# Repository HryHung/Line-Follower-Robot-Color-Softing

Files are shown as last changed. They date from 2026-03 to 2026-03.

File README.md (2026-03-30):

# Line Following AGV Robot (Color-Based Distribution)

Mobile robot designed for line tracking and automatic goods sorting based on color.  
This project demonstrates practical applications of control theory, embedded systems, and mechatronics design.

---
 robot
##  Overview

This project focuses on building a line-following robot with:

- Embedded firmware for real-time control  
- Line tracking using IR sensor array  
- Color detection for decision making  
- Autonomous navigation and delivery  

---

##  Guide

- You will need 2 esp32 devkit: 1 for robot & 1 for the controller
- Custom PCB is not requirement, you can replace by pegboard
- The Robot base is CNC
aluminium, you can replace by other material like: mica, 3d printed,...
- Matlab file are only for PID and visual check, you guys with need to PID your DC motor before run.

---

##  System Architecture

### Hardware

- Differential drive mobile platform  
- DC motors with encoders  
- IR sensor array (line detection)  
- Color sensor (Red / Blue detection)  
- Motor driver (TB6612FNG)  
- Microcontroller (STM32 / ESP32)  
- Battery + power management  

### Software Stack

```
[ High-Level Logic ]
        ↓
[ Decision Making (Color Detection) ]
        ↓
[ Line Tracking Algorithm ]
        ↓
[ PID Motor Control ]
        ↓
[ Hardware Drivers (PWM / ADC / GPIO) ]
```

---

##  Features

- Accurate line following (±3 mm error)  
- Autonomous color-based sorting  
- PID-based motor control  
- Modular hardware & software design  
- Suitable for robotics learning and R&D  

---

##  Technologies

- Embedded C  
- ESP32  
- PWM / ADC / GPIO  
- SolidWorks
- MATLAB / Simulink (modeling & control)  

---

##  Control Concept

- Line position estimated using weighted sensor readings  
- PID controller used for trajectory correction  
- State machine handles robot behavior:

```
Idle → Follow Line → Detect Load → Detect Color
     → Navigate → Stop at Destination
```

---

##  Specifications

- Speed ≥ 0.1 m/s  
- Line width: 26 mm  
- Tracking error: ±3 mm  
- Stopping error: ±5 mm  
- Load capacity: ~1 kg

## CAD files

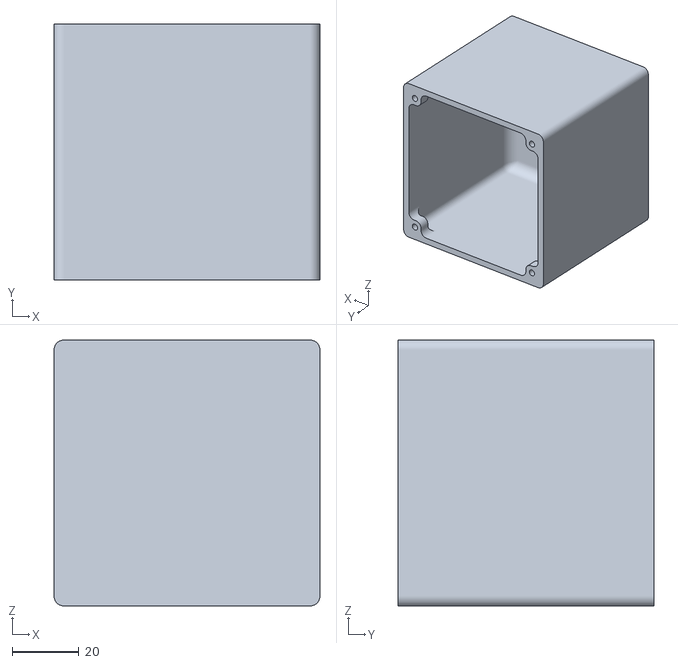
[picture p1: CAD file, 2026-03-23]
Mechanical/Robot V2/Thân khối hàng_màu đỏ.STL
80.0 x 77.0 x 80.0

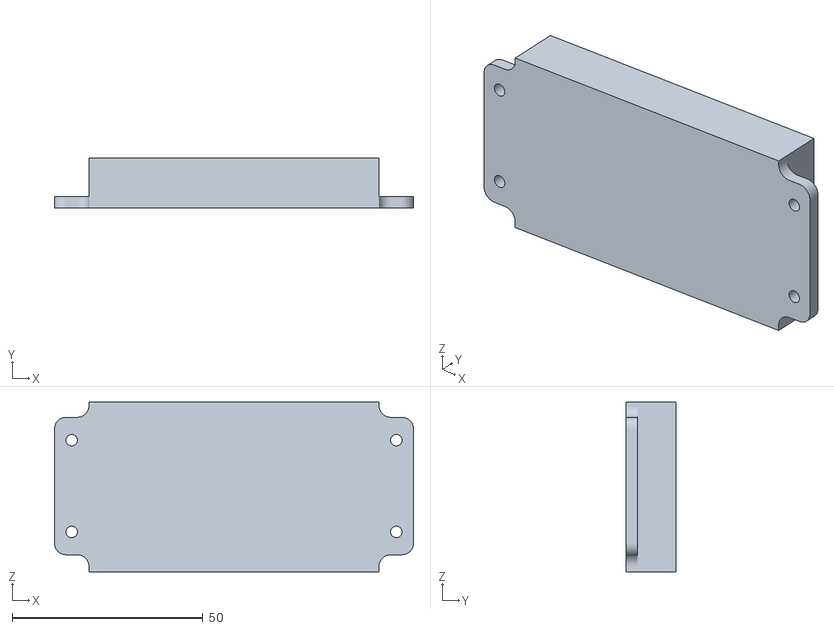
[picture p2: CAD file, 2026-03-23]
Mechanical/Robot V2/Gá pin.STL
94.0 x 13.0 x 44.5

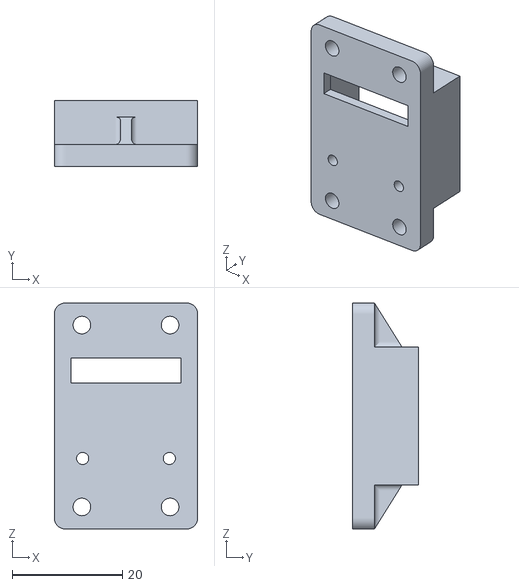
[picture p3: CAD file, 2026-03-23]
Mechanical/Robot V2/Gá cảm biến màu sắc.STL
26.0 x 12.0 x 41.0

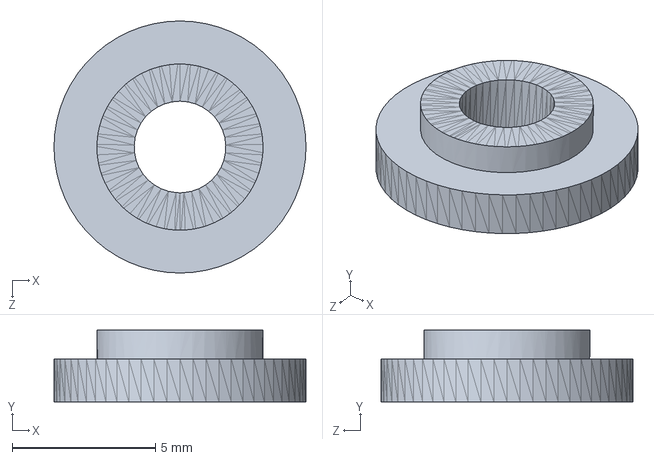
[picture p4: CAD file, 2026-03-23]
Mechanical/Chêm PCB dò line (1).SLDPRT
8.80 x 2.50 x 8.80 mm

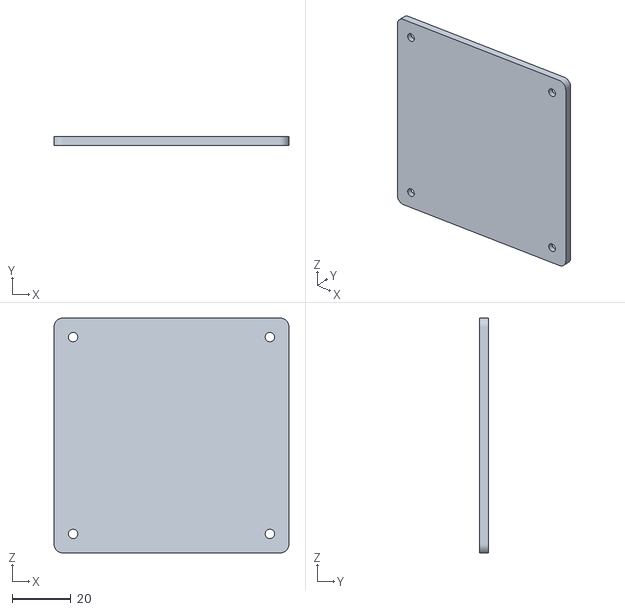
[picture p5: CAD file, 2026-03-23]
Mechanical/Robot V2/Nắp khối hàng_màu xanh.STL
80.0 x 3.00 x 80.0

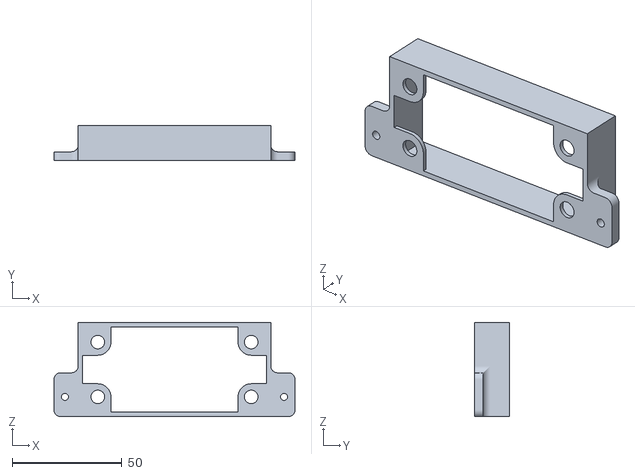
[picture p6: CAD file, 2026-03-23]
Mechanical/Che cảm biến.STL
110.0 x 16.0 x 43.0

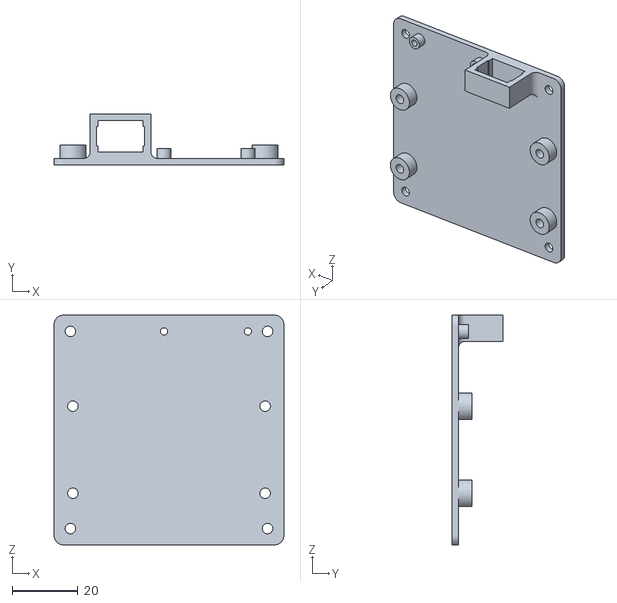
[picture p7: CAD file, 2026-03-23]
Mechanical/Robot V2/PCB dưới.SLDPRT.STL
70.0 x 15.5 x 70.0

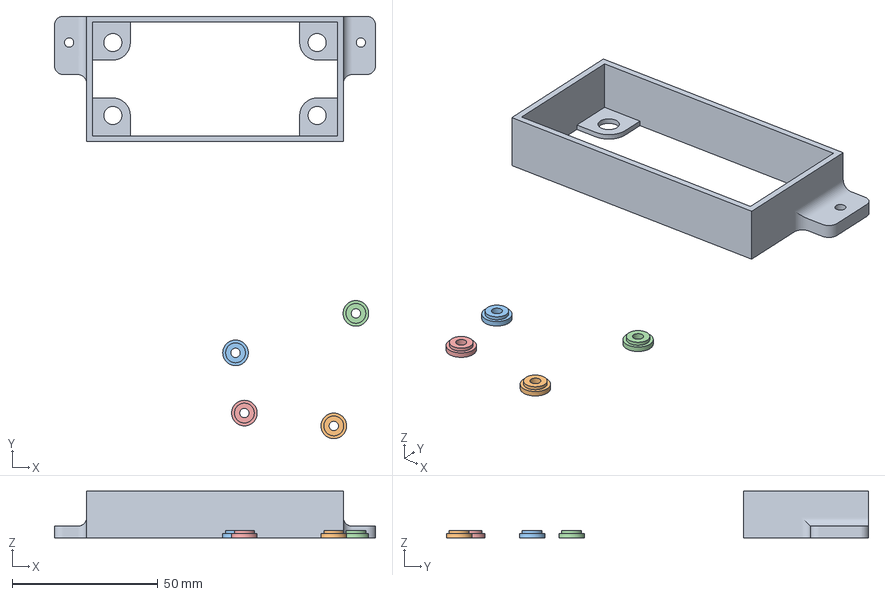
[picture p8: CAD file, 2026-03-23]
Mechanical/Chêm PCB dò line.3mf
110.0 x 144.8 x 16.0 mm
Che cảm biến.STL
Chêm PCB dò line.STL x 4

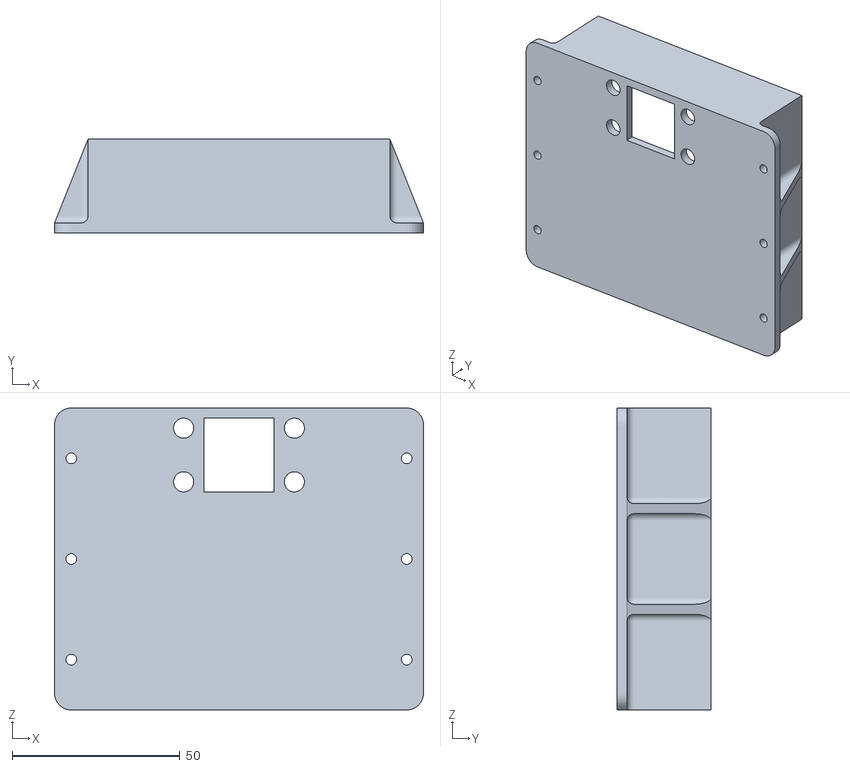
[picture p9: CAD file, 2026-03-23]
Mechanical/Robot V2/Box đựng hàng.STL
110.0 x 28.0 x 90.0

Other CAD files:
Electronics/FIXED.dwg
Electronics/BV DIEN FINAL EIC PT V1.dwg
Mechanical/Ban_ve_lap.dwg
Electronics/Final - BV DIEN FINAL EIC PT V1.dwg
Mechanical/Chêm PCB dò line (2).STL
Mechanical/Che cảm biến (1).STL
Mechanical/Chêm PCB dò line (1).STL
Mechanical/Chêm PCB dò line.STL

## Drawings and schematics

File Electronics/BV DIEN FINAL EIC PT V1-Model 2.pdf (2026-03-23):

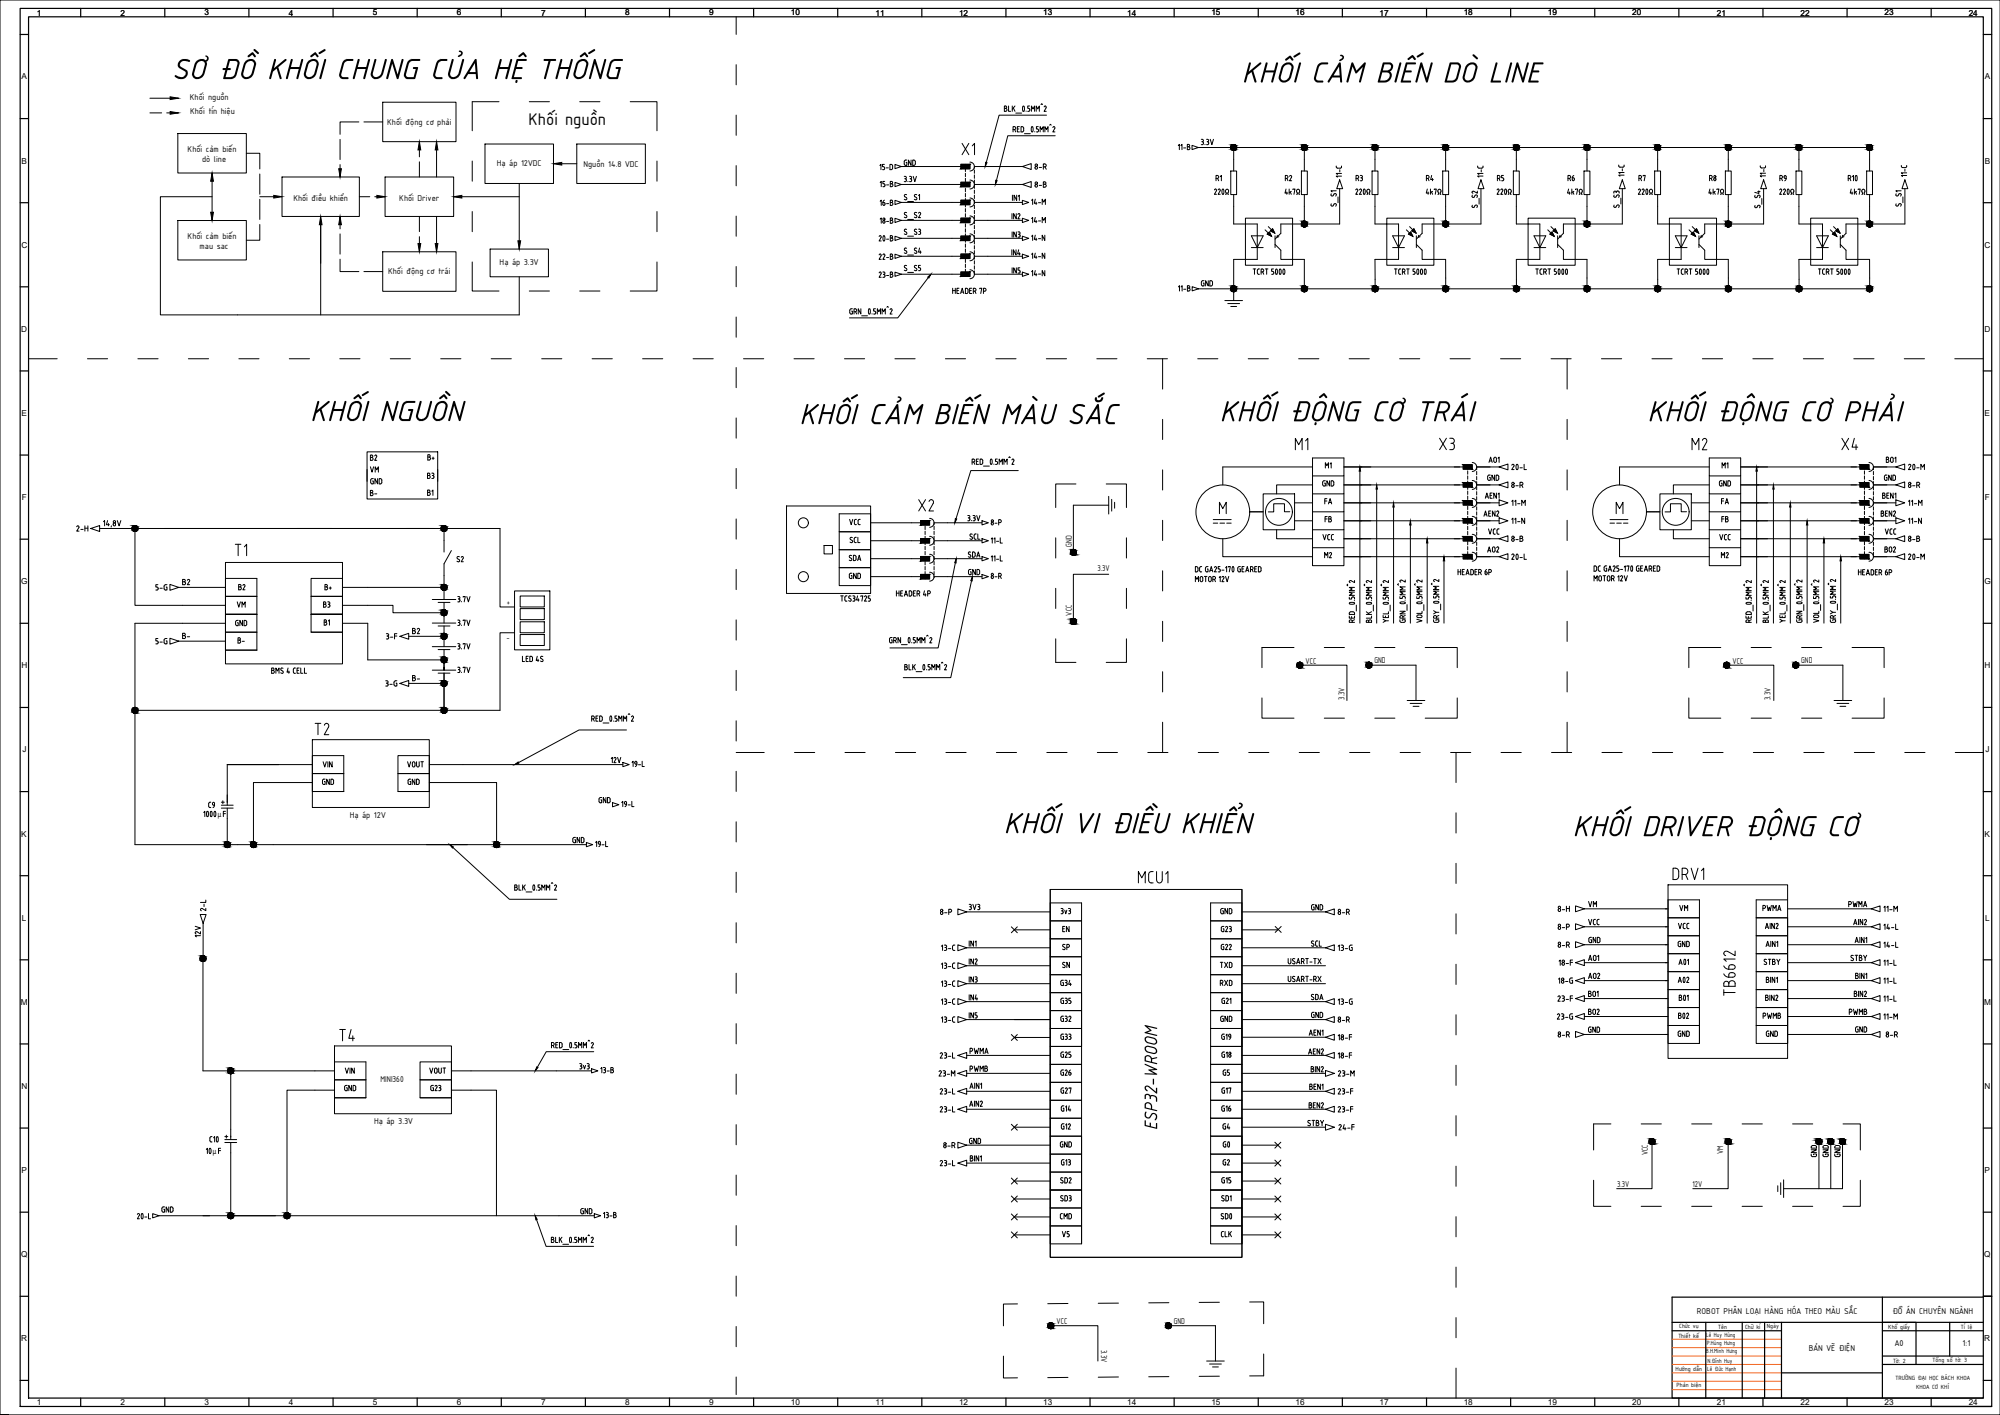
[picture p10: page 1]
24 ABDCHGEFNPJKMLRQ; ABDCHGEFNPJKMLRQ ROBOT PHÂN LOẠI HÀNG HÓA THEO MÀU SẮC BẢN VẼ ĐIỆN; TRƯỜNG ĐẠI HỌC BÁCH KHOA KHOA CƠ KHÍ Chức vụ; Tên; Ngày Thiết kế Hướng dẫn Phản biện; ĐỒ ÁN CHUYÊN NGÀNH Khổ giấy; Tổng số tờ: 3 Chữ kí KHỐI CẢM BIẾN DÒ LINE KHỐI DRIVER ĐỘNG CƠ KHỐI ĐỘNG CƠ TRÁI; KHỐI ĐỘNG CƠ PHẢI KHỐI VI ĐIỀU KHIỂN Khối cảm biến dò line Khối cảm biến mau sac; Khối điều khiển; Khối Driver Khối động cơ phải Khối động cơ trái; Hạ áp 12VDC Khối nguồn Khối tín hiệu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

GND +- μ Nguồn 14.8 VDC VCC GND

3.3V GND KHỐI CẢM BIẾN MÀU SẮC

ESP32-WROOM Hạ áp 3.3V MINI360 Lê Huy Hùng

P.Hùng Hưng
B.H.Minh Hưng
N.Đình Huy
Lê Đức Hạnh

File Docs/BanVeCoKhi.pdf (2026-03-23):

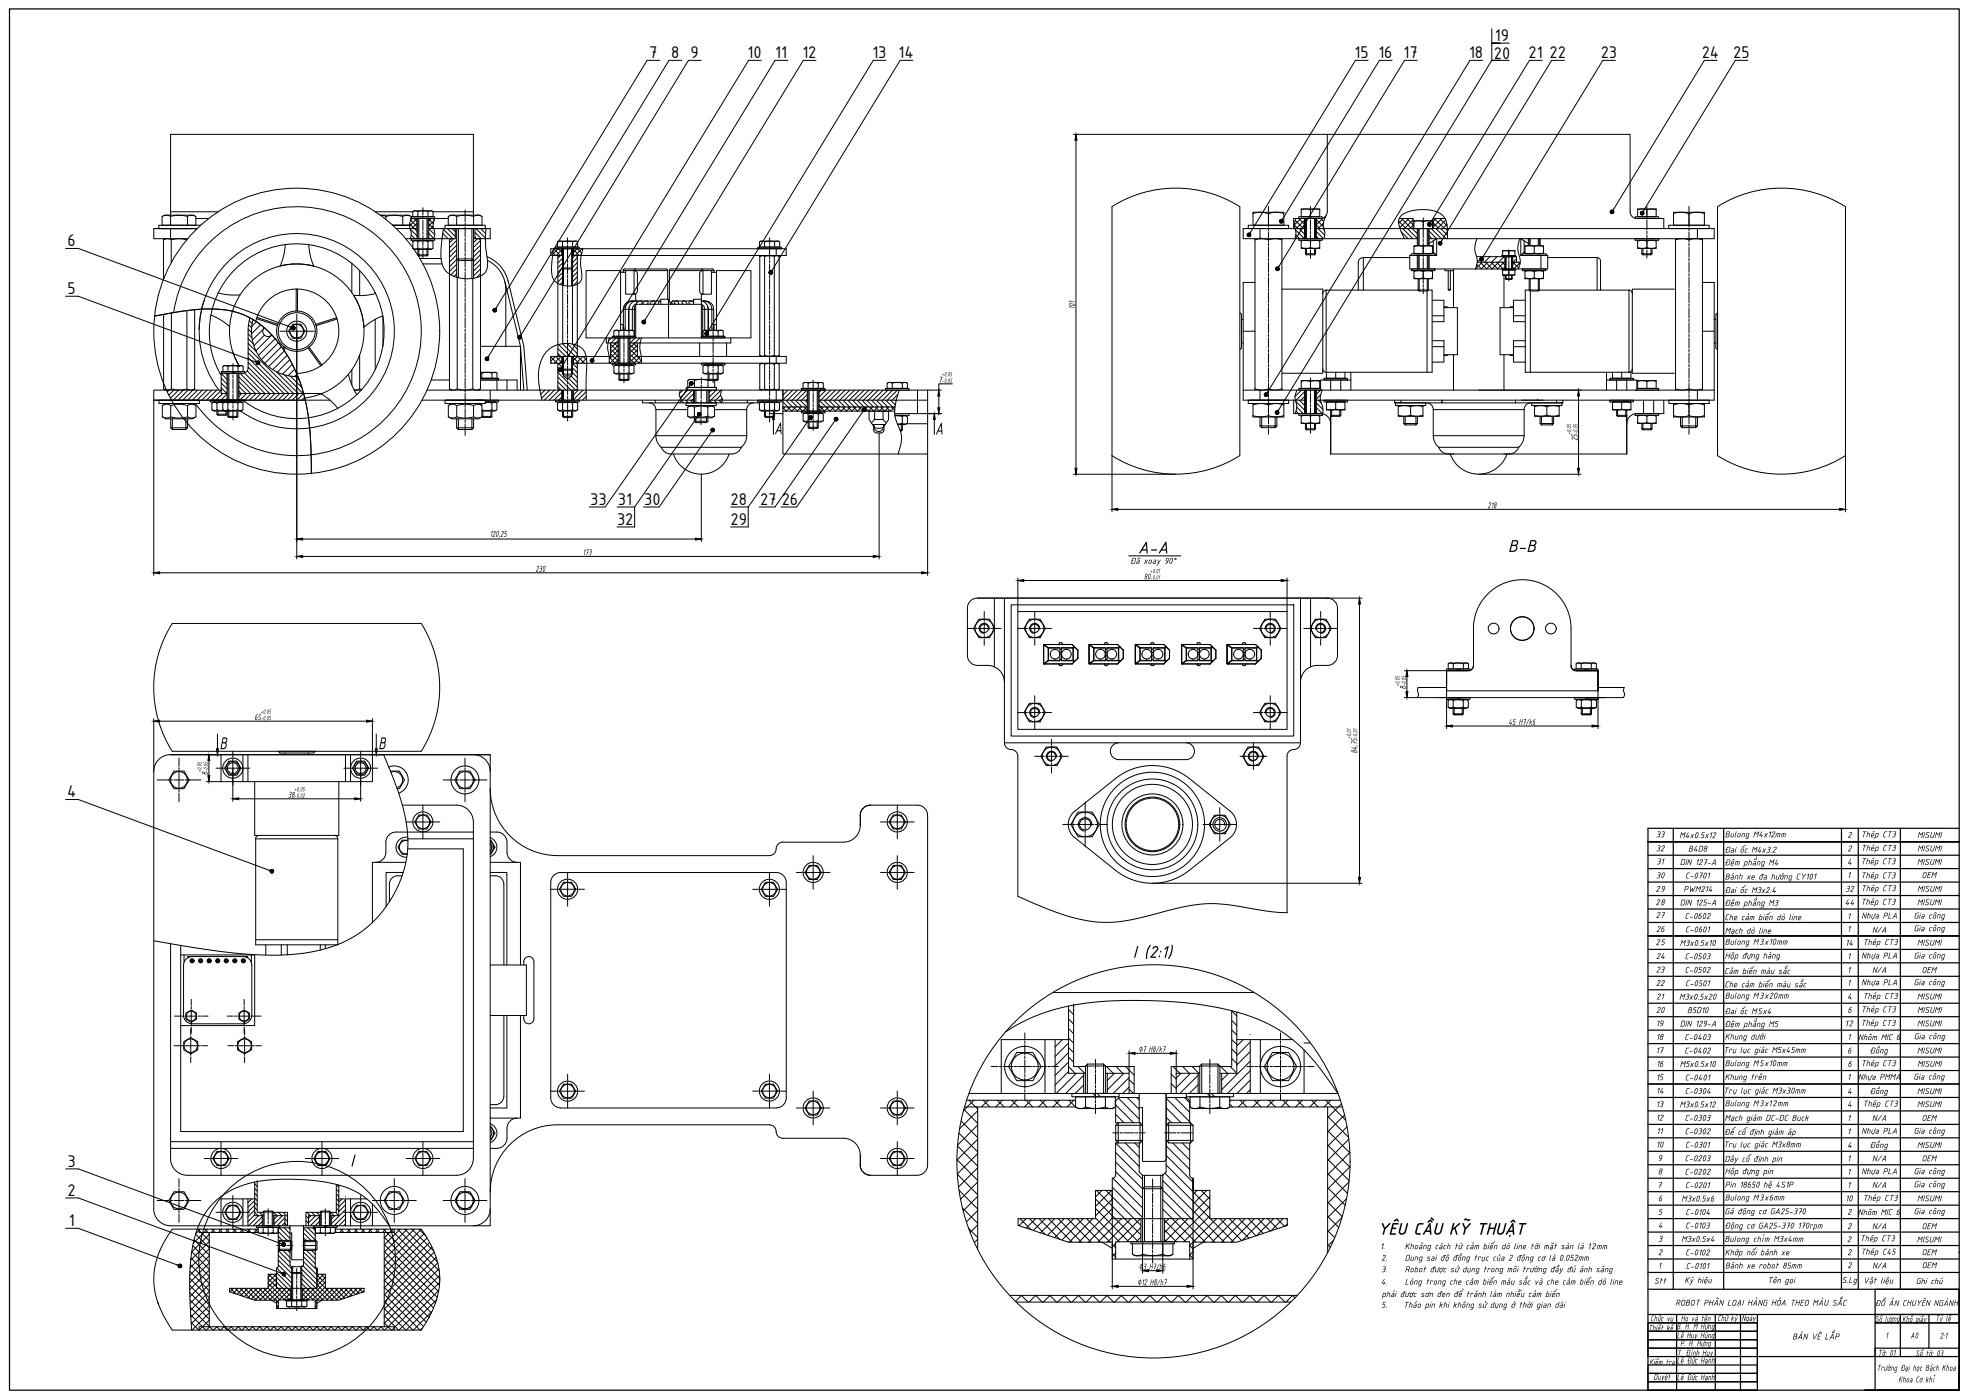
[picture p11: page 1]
Kiểm tra; Chức vụ 1234567891011121314151617181920 Stt; Ký hiệu; Tên gọi; Vật liệu; Ghi chú Động cơ GA25-370 170rpm Khớp nối bánh xe; OEM Nhôm MIC 6; Gia công Pin 18650 hệ 4S1P Gá động cơ GA25-370; 2 Trụ lục giác M3x8mm; Thép C45 N/A; MISUMI OEM Đồng N/A; Gia công Trụ lục giác M3x30mm; Đồng; MISUMI BẢN VẼ LẮP

-0,05 65+0,05 -0,05 38+0,05 -0,02 120,25 173 7+0,05 -0,05 16 9 10 11 12 13 14 15 16 17 18 21 22 23 24 25 Bánh xe robot 85mm 2 N/A OEM Bulong M3x6mm 10 Thép CT3 MISUMI Hộp đựng hàng Che cảm biến màu sắc 112 Nhựa PLA Đệm phẳng M5 MISUMI Gia công Thép CT3 1 Nhựa PLA Gia công Dây cố định pin 1 N/A OEM Đế cố định giảm áp Mạch giảm DC-DC Buck 1 N/A OEM 1 Nhựa PLA Gia công Bulong M3x12mm 4 Thép CT3 MISUMI Cảm biến màu sắc 1 N/A OEM Khung trên 1 Nhựa PMMA Gia công 1920 Bulong M3x20mm 4 Thép CT3 MISUMI Bulong M3x10mm 14 Thép CT3 MISUMI Che cảm biến dò line 1 Nhựa PLA Gia công 33 30 27 26 Mạch dò line 1 N/A Gia công Bánh xe đa hướng CY101 1 Thép CT3 OEM 29 Đai ốc M3x2.4 32 Thép CT3 MISUMI Đệm phẳng M3 44 Thép CT3 MISUMI 31 32 Đai ốc M4x3.2 2 Thép CT3 MISUMI Đệm phẳng M4 4 Thép CT3 MISUMI Bulong M4x12mm 2 Thép CT3 MISUMI 28293031 3233 C-0101 C-0102 M3x0.5x4 C-0103 C-0104 M3x0.5x6 C-0201 C-0202 C-0203 C-0301 C-0302 C-0303 M3x0.5x12 C-0304 C-0401 M5x0.5x10 C-0402 C-0403 DIN 129-A B5D10 M3x0.5x20 C-0501 C-0502 C-0503 M3x0.5x10 C-0601 C-0602 DIN 125-A PWM214 C-0701 DIN 127-A B4D8 M4x0.5x12 ĐỒ ÁN CHUYÊN NGÀNH 1 A0 Tờ: 01 Số tờ: 03 230

ROBOT PHÂN LOẠI HÀNG HÓA THEO MÀU SẮC

Tỷ lệ 2:1 Khổ giấy Thiết kế

Họ và tên | Chữ ký | Ngày | Số lượng

Trường Đại học Bách Khoa

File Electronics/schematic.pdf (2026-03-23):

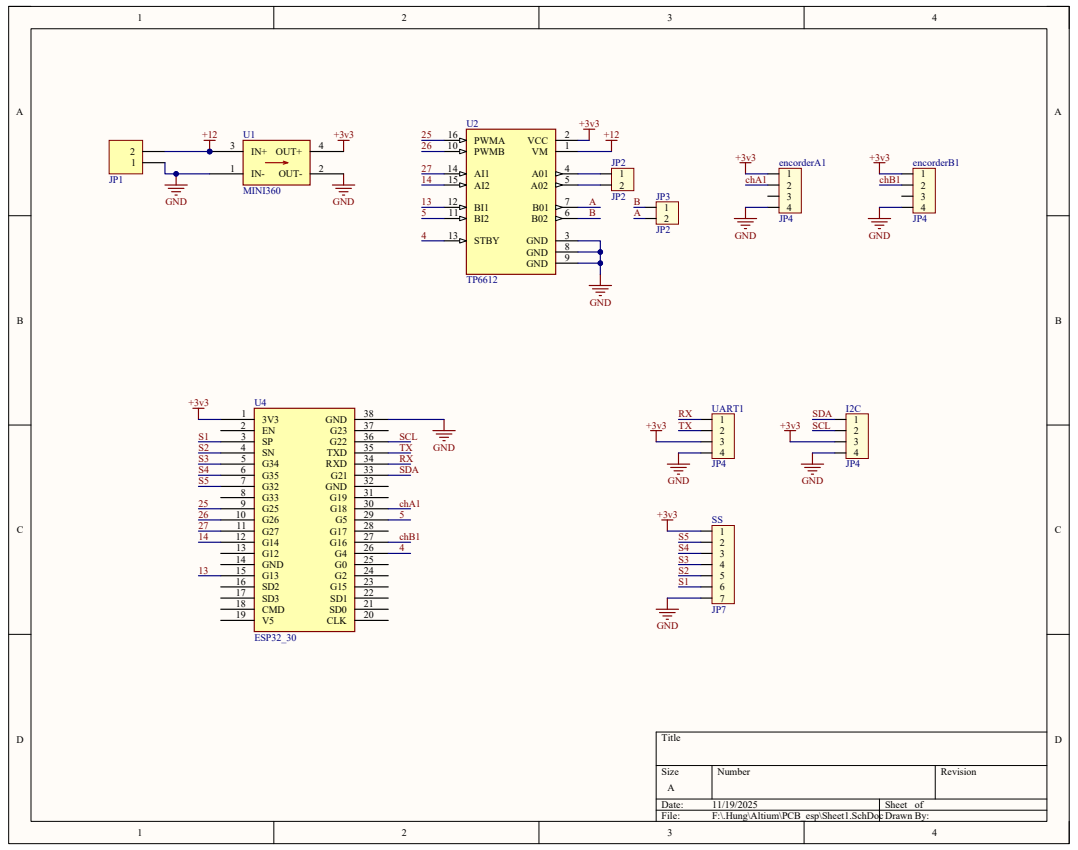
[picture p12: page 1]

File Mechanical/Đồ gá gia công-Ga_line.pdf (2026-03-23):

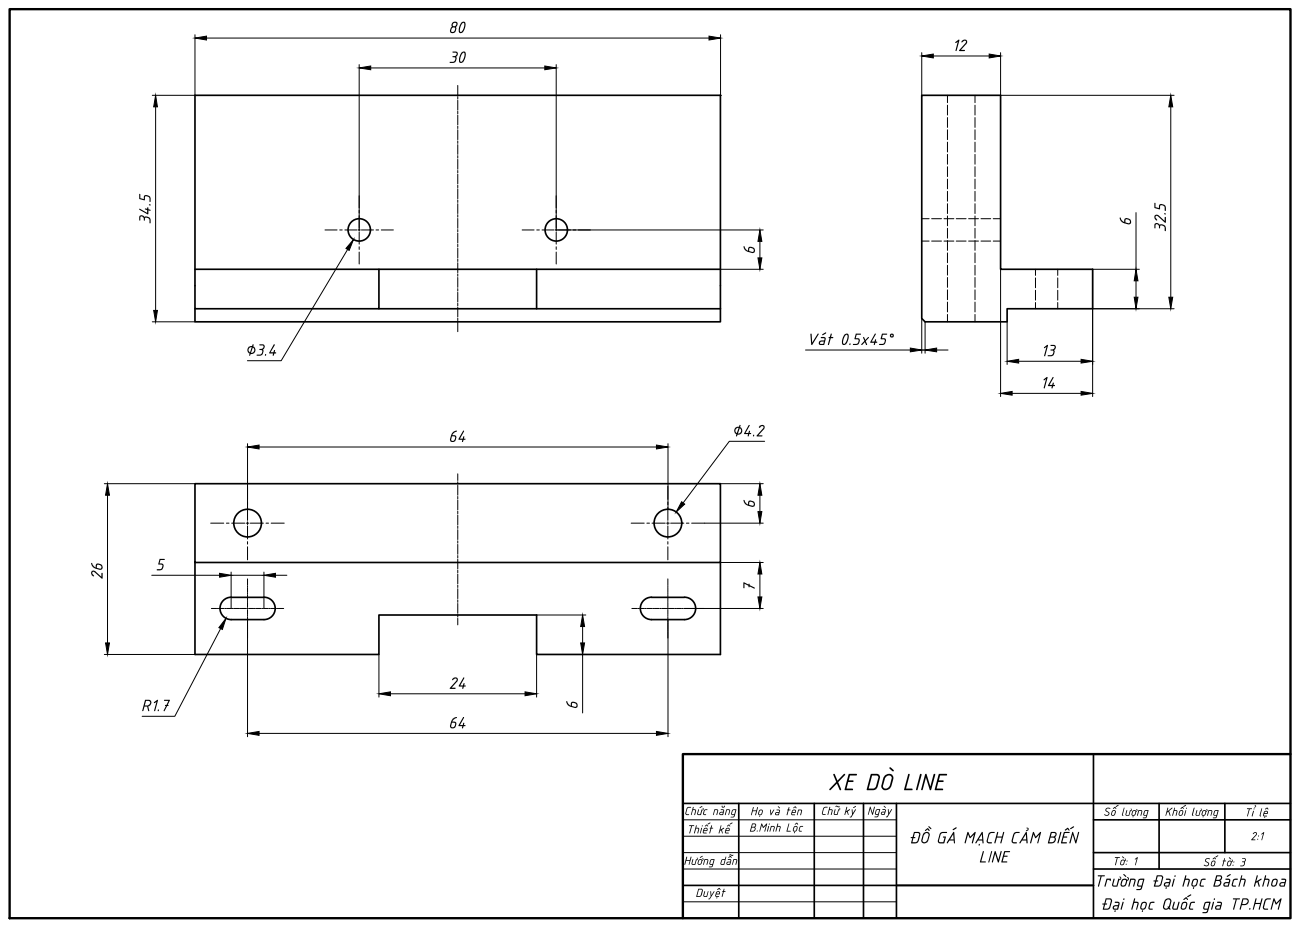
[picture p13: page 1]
Hướng dẫn; Vát 0.5x45°

XE DÒ LINE

Chức năng | Họ và tên | Chữ ký | Ngày | ĐỒ GÁ MẠCH CẢM BIẾN LINE | Số lượng | Khối lượng | Tỉ lệ
Thiết kế | B.Minh Lộc | | | | | | 2:1

Trường Đại học Bách khoa
Đại học Quốc gia TP.HCM

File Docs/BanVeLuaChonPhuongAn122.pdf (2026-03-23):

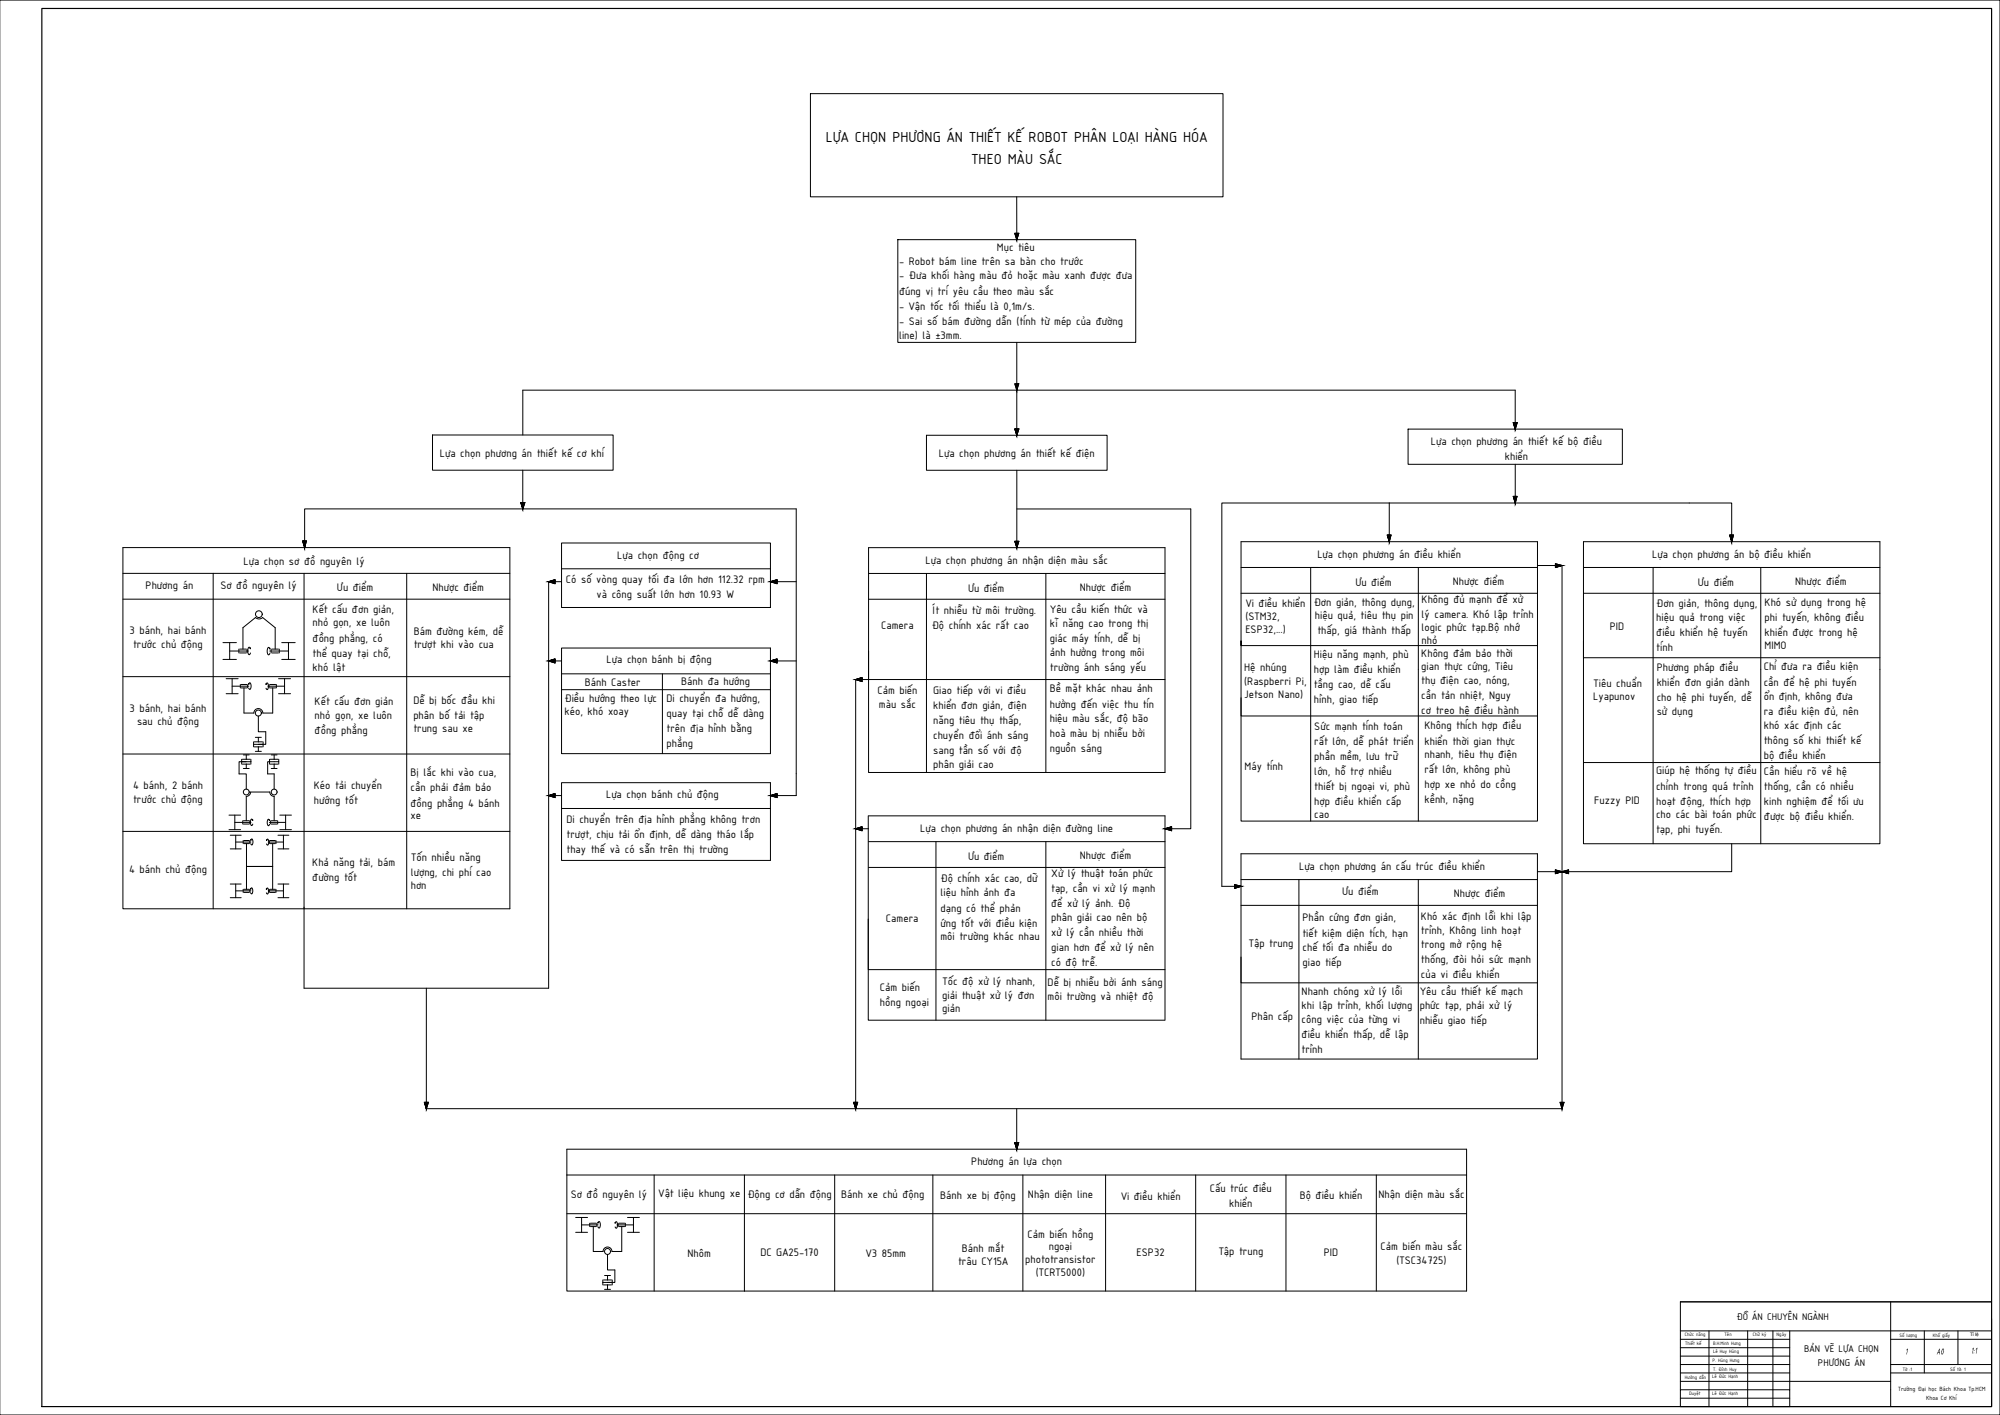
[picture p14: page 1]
1:1 ĐỒ ÁN CHUYÊN NGÀNH BẢN VẼ LỰA CHỌN PHƯƠNG ÁN Chức năng; Tên; Chữ ký; Ngày B.H.Minh Hưng Duyệt; Số lượng; Khổ giấy; Tỉ lệ Trường Đại học Bách Khoa Tp.HCM Khoa Cơ Khí Tờ :1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

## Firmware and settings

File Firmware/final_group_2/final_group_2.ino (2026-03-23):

/*
 * ESP32 ROBOT – FINAL FULL VERSION (UPDATED LOGIC)
 * =================================================
 * - Sequence: SPECIAL CONDITIONS → LINE FOLLOW → SPEED PID → FEEDBACK
 * - Pickup Zone + cargo_type Logic fully rewritten and optimized.
 * Hung - 20/11
 */

#include <Arduino.h>
#include <Wire.h>
#include <Adafruit_TCS34725.h>

// ==========================================================
// 1. HARDWARE
// ==========================================================

// Motor pins
const int PIN_AIN1 = 14, PIN_AIN2 = 27, PIN_PWMA = 25;
const int PIN_BIN1 = 13, PIN_BIN2 = 5, PIN_PWMB = 26;
const int PIN_STBY = 4;

const int PIN_ENC_A_1 = 17, PIN_ENC_B_1 = 16;
const int PIN_ENC_A_2 = 18, PIN_ENC_B_2 = 19;

// Line sensors
const int S1 = 36, S2 = 39, S3 = 34, S4 = 35, S5 = 32;

// Color sensor
Adafruit_TCS34725 tcs(
  TCS34725_INTEGRATIONTIME_50MS,
  TCS34725_GAIN_4X
);

// PWM + Encoder
const int PWM_FREQ = 20000;
const int PWM_RES = 10;
const float PWM_MAX = 1023.0;
const int CPR = 390;
const float DT_MS = 50;

// --- Measured RPM ---
double rpm_meas_1 = 0;
double rpm_meas_2 = 0;

// ==========================================================
// 2. PID PARAMETERS (RESTORED VALUES)
// ==========================================================

// Inner loop (Speed PI)
double Kp_1 = 0.19, Ki_1 = 11.0;
double Kp_2 = 0.20, Ki_2 = 11.0;

double integ_1 = 0, integ_2 = 0;

// Outer loop (Line PID)
double base_rpm = 155.0;

double Kp_line = 5.0;
double Ki_line = 0.75;
double Kd_line = 1.3;

double err_line = 0, last_err_line = 0, integ_line = 0;

// Sensors calibration
int rawMin[5] = {53, 43, 30, 33, 27};
int rawMax[5] = {3200, 2965, 2748, 2684, 2691};

//int rawMin[5] = {28, 35, 34, 43, 44};
//int rawMax[5] = {2600, 2328, 2138, 2753, 2821};

int weight[5]  = {-20, -10, 0, 10, 20};
int norm_sensor[5];

// Color calib
float redCalib[3]  = {47.8, 20.9, 14.9};
float blueCalib[3] = {38.0, 45.6, 38.6};
float unkCalib[3]  = {26.0, 24.0, 16.8};
const float COLOR_THRESHOLD = 150.0;

// Encoder
volatile long encCount1 = 0, encCount2 = 0;
long lastEnc1 = 0, lastEnc2 = 0;

unsigned long lastLoopTime = 0;

// ==========================================================
// 3. STATE MACHINE
// ==========================================================
enum RobotState {
  STATE_STOP,
  STATE_MOVING,
  STATE_LOADING,
  STATE_EXIT_PICKUP,
  STATE_TURN_LEFT,
  STATE_TURN_RIGHT
};

RobotState currentState = STATE_STOP;
unsigned long stateStart = 0;

// ==========================================================
// 4. cargo_type LOGIC VARIABLES
// ==========================================================
bool isHasCargo = false;  // Already scanned?
int cargo_type = 0;           // 0: none, 1: red, 2: blue

String inLine; bool haveLine = false;

// ==========================================================
// HELPERS
// ==========================================================
void IRAM_ATTR encISR1() {
  if (digitalRead(PIN_ENC_B_1)) encCount1++; else encCount1--;
}
void IRAM_ATTR encISR2() {
  if (digitalRead(PIN_ENC_B_2)) encCount2++; else encCount2--;
}

void motorDrive(int pin1, int pin2, int pwmPin, int val) {
  val = constrain(val, -1023, 1023);

  if (val > 0) {
    digitalWrite(pin1, HIGH); digitalWrite(pin2, LOW);
  } else if (val < 0) {
    digitalWrite(pin1, LOW); digitalWrite(pin2, HIGH);
  } else {
    digitalWrite(pin1, LOW); digitalWrite(pin2, LOW);
  }

  ledcWrite(pwmPin, abs(val));
}

void setMotors(int u1, int u2) {
  motorDrive(PIN_AIN1, PIN_AIN2, PIN_PWMA, u1);
  motorDrive(PIN_BIN1, PIN_BIN2, PIN_PWMB, u2);
}

int clampMap(int x, int in_min, int in_max, int out_min, int out_max) {
  if (x <= in_min) return out_min;
  if (x >= in_max) return out_max;
  return (long)(x - in_min) * (out_max - out_min) / (in_max - in_min) + out_min;
}

void readLineSensors() {
  int pins[5] = {S1, S2, S3, S4, S5};
  for (int i = 0; i < 5; i++)
    norm_sensor[i] = clampMap(analogRead(pins[i]), rawMin[i], rawMax[i], 0, 1000);
}

double getLineError() {
  long sumW = 0, sumV = 0;
  for (int i = 0; i < 5; i++) {
    sumW += norm_sensor[i] * weight[i];
    sumV += norm_sensor[i];
  }
  if (sumV < 300) return last_err_line;
  return (double)sumW / sumV;
}

float getDist(float r, float g, float b, float calib[3]) {
  return sqrt(pow(r - calib[0], 2) + pow(g - calib[1], 2) + pow(b - calib[2], 2));
}

int detectColorRaw() {
  
  uint16_t r, g, b, c;
  tcs.getRawData(&r, &g, &b, &c);

  // Convert to float (giống print_color)
  float fR = r;
  float fG = g;
  float fB = b;

  // Tính khoảng cách
  float dRed  = getDist(fR, fG, fB, redCalib);
  float dBlue = getDist(fR, fG, fB, blueCalib);
  float dUnk  = getDist(fR, fG, fB, unkCalib);

  // Chọn min
  float minDist = dRed;
  int color = 1;   // RED

  if (dBlue < minDist) {
    minDist = dBlue;
    color = 2;     // BLUE
  }
  if (dUnk < minDist) {
    minDist = dUnk;
    color = 0;     // UNKNOWN
  }

  return color;
}


void resetPID() {
  integ_1 = integ_2 = 0;
  integ_line = 0;
  last_err_line = 0;
}

// ==========================================================
// SETUP
// ==========================================================
void setup() {
  Serial.begin(115200);
  delay(200);

  analogReadResolution(12);
  Wire.begin();

  if (!tcs.begin()) {
    Serial.println("Color Sensor FAIL");
    while (1);
  }
  tcs.setInterrupt(false); // Enable sensor

  pinMode(PIN_STBY, OUTPUT);
  digitalWrite(PIN_STBY, HIGH);

  pinMode(PIN_AIN1, OUTPUT); pinMode(PIN_AIN2, OUTPUT);
  pinMode(PIN_BIN1, OUTPUT); pinMode(PIN_BIN2, OUTPUT);

  pinMode(PIN_ENC_A_1, INPUT);
  pinMode(PIN_ENC_B_1, INPUT);
  pinMode(PIN_ENC_A_2, INPUT);
  pinMode(PIN_ENC_B_2, INPUT);

  ledcAttach(PIN_PWMA, PWM_FREQ, PWM_RES);
  ledcAttach(PIN_PWMB, PWM_FREQ, PWM_RES);

  attachInterrupt(digitalPinToInterrupt(PIN_ENC_A_1), encISR1, RISING);
  attachInterrupt(digitalPinToInterrupt(PIN_ENC_A_2), encISR2, RISING);

  Serial.println("Press: g to go  || s to stop");
}

// ==========================================================
// MAIN LOOP
// ==========================================================
void loop() {

  // ============LOOP: 1. START/STATE_STOP=========
  while (Serial.available()) {
    char c = (char)Serial.read();
    if (c == '\n' || c == '\r') {
      if (inLine.length()) haveLine = true;
    } else inLine += c;
  }

  if (haveLine) {
    inLine.trim();
    if (inLine == "g") {currentState = STATE_MOVING; cargo_type = 0; isHasCargo = false;}
    else if (inLine == "s") { currentState = STATE_STOP; setMotors(0,0); }
    haveLine = false;
    inLine = "";
  }

  // ========== LOOP: 2. DATA =========
  unsigned long now = millis();
  if (now - lastLoopTime < DT_MS) return;

  float dt = (now - lastLoopTime) / 1000.0f;
  lastLoopTime = now;

  // Encoder
  long c1 = encCount1, c2 = encCount2;
  long dp1 = c1 - lastEnc1; lastEnc1 = c1;
  long dp2 = c2 - lastEnc2; lastEnc2 = c2;

  double rpm1 = (dp1 / dt) * 60.0 / CPR;
  double rpm2 = (dp2 / dt) * 60.0 / CPR;

  rpm_meas_1 = rpm1;
  rpm_meas_2 = rpm2;

  // Read line sensors
  readLineSensors();

  // Shortcut vars
  int s1 = norm_sensor[0];
  int s2 = norm_sensor[1];
  int s3 = norm_sensor[2];
  int s4 = norm_sensor[3];
  int s5 = norm_sensor[4];

  // =============LOOP: 3. SPECIAL CASE CHECK===========

  bool isPickupZone = ((s2 >= 400 && s3 >= 400 && s4 >= 400));
  bool iscargo_type = (s3 <= 300 && s1 >= 700 && s5 >= 700);
  bool isFinish = (s1<200 && s2<200 && s3<200 && s4<200 && s5<200); 

  //A. Check finish
  if (currentState == STATE_MOVING && isFinish) {
       setMotors(-20,-20);
       currentState = STATE_STOP; 
       Serial.println("STATE_STOP SHIPPING");
       return;
  }

  //B. Check Pickup Zone
  if (currentState == STATE_MOVING && !isHasCargo && isPickupZone) {
    setMotors(-20,-20);
    resetPID();
    Serial.println("Arrive Pickup_Zone !!!");

    delay(2000);

    Serial.println("START LOADING...");

    currentState = STATE_LOADING;
    stateStart = now;
    return;
  }

  //C. Check Intersection
  if (currentState == STATE_MOVING && iscargo_type) {
    
    setMotors(0,0);
    resetPID();

    if (!isHasCargo) {
      Serial.println(" HADN'T LOADING → STATE_STOP");
      currentState = STATE_STOP;
      return;
    }

    if (cargo_type == 1) {
      Serial.println("==> RED → LEFT");
      currentState = STATE_TURN_LEFT;
    } else if (cargo_type == 2) {
      Serial.println("==> BLUE → RIGHT");
      currentState = STATE_TURN_RIGHT;
    }

    stateStart = now;
    return;
  }

  // =============LOOP: 4.ROBOT STATE=========
  switch (currentState) {

    //a. STATE_STOP
    case STATE_STOP:
      setMotors(-20,-20);
      break;

    //
    case STATE_LOADING: {
      setMotors(-20, -20);

      static int lastColor = 0;        // màu ở chu kỳ trước
      static unsigned long colorStart = 0;  // thời điểm bắt đầu giữ 1 màu
      static bool waitingMsgShown = false;

      int cargo_color = detectColorRaw();   // 0 = UNKNOWN, 1 = RED, 2 = BLUE

      if (!waitingMsgShown) {
        Serial.println("WAITING FOR LOADING...");
        waitingMsgShown = true;
      }

      // Nếu UNKNOWN → không tính, reset và tiếp tục chờ
      if (cargo_color == 0) {
        lastColor = 0;
        colorStart = 0;
        Serial.println("WAITING FOR LOADING...");
        break;
      }

      // Nếu màu thay đổi → reset timer
      if (cargo_color != lastColor) {
        lastColor = cargo_color;
        colorStart = now;  // bắt đầu đếm lại
        // Debug:
        if (cargo_color == 1) Serial.println("RED → FINISH LOADING IN 3S...");
        if (cargo_color == 2) Serial.println("BLUE → FINISH LOADING IN 3S...");
      }

      // Kiểm tra giữ màu đủ 3s
      if (colorStart > 0 && (now - colorStart >= 3000)) {

        cargo_type = cargo_color;
        isHasCargo = true;

        if (cargo_color == 1) Serial.println("RECEIVED - RED CARGO");
        else if (cargo_color == 2) Serial.println("RECEIVED - BLUE CARGO");

        // Reset biến
        lastColor = 0;
        colorStart = 0;
        waitingMsgShown = false;

        delay(500);
        currentState = STATE_EXIT_PICKUP;
        stateStart = now;
      }

    }
    break;


    // --------------------------------------------------------
    case STATE_EXIT_PICKUP:
      setMotors(250, 250);
      if (now - stateStart >= 400) {
        currentState = STATE_MOVING;
        resetPID();
      }
      break;

    // --------------------------------------------------------
    case STATE_TURN_LEFT:
      setMotors(-250, 250);
      if (now - stateStart >= 100) {
        setMotors(50,50);
        currentState = STATE_MOVING;
        resetPID();
      }
      break;

    // --------------------------------------------------------
    case STATE_TURN_RIGHT:
      setMotors(150, -150);
      if (now - stateStart >= 100) {
        setMotors(50,50);
        currentState = STATE_MOVING;
        resetPID();
      }
      break;

    // --------------------------------------------------------
    case STATE_MOVING: {
      // LINE PID
      err_line = getLineError();

      double P = Kp_line * err_line;
      integ_line += err_line * dt;
      integ_line = constrain(integ_line, -50, 50);
      double I = Ki_line * integ_line;
      double D = Kd_line * (err_line - last_err_line) / dt;
      last_err_line = err_line;

      double steer = P + I + D;

      double set1 = base_rpm + steer;
      double set2 = base_rpm - steer;

      // SPEED PID
      integ_1 += (set1 - rpm_meas_1) * Ki_1 * dt;
      integ_1 = constrain(integ_1, -1023, 1023);
      double u1 = Kp_1*(set1 - rpm_meas_1) + integ_1;

      integ_2 += (set2 - rpm_meas_2) * Ki_2 * dt;
      integ_2 = constrain(integ_2, -1023, 1023);
      double u2 = Kp_2*(set2 - rpm_meas_2) + integ_2;

      setMotors((int)u1, (int)u2);
    }
    break;
  }


  // ================================================================
  // 4. FEEDBACK / DEBUG
  // ================================================================
  static unsigned long lastPrint = 0;
  if (now - lastPrint > 1000) {
    lastPrint = now;

    Serial.print(" | Err: ");   Serial.print(err_line, 2);
    Serial.print(" | STATUS "); Serial.print(currentState); 
    Serial.printf("| S:%d %d %d %d %d | inter:%d | rpm:%.0f %.0f\n",
      s1, s2, s3, s4, s5,
      cargo_type,
      rpm_meas_1, rpm_meas_2

    );
  }
}

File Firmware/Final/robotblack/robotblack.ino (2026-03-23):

/*
 * ESP32 ROBOT - SLAVE (UPDATED KINEMATIC OBSERVER)
 * ==================================================
 * - Logic cũ: GIỮ NGUYÊN
 * - Update: Hàm getErrorCenter dùng động học ngược + Lọc nhiễu
 */

#include <Arduino.h>
#include <Wire.h>
#include <Adafruit_TCS34725.h>
#include <esp_now.h>
#include <WiFi.h>

// ===================== ESP-NOW =====================

uint8_t masterAddress[] = {0xFC, 0xE8, 0xC0, 0xDF, 0x73, 0x7C}; // <--- GIỮ NGUYÊN MAC CỦA BẠN

typedef struct struct_telemetry {
  int status;       
  int cargoColor;   
  float rpmLeft;
  float rpmRight;
  float errorLine;
  float errorCenter;   // Giá trị tâm xe mới
  int s1; int s2; int s3; int s4; int s5;
  float biggestError;
  unsigned long travelTime;
} struct_telemetry;

typedef struct struct_command {
  char cmd;
} struct_command;

struct_telemetry myData;
struct_command incomingCmd;

volatile bool newCommandReceived = false;
volatile char commandChar = ' ';

// ===================== HARDWARE =====================
const int PIN_AIN1 = 14, PIN_AIN2 = 27, PIN_PWMA = 25;
const int PIN_BIN1 = 13, PIN_BIN2 = 5, PIN_PWMB = 26;
const int PIN_STBY = 4;
const int PIN_ENC_A_1 = 16, PIN_ENC_B_1 = 17;
const int PIN_ENC_A_2 = 19, PIN_ENC_B_2 = 18;
const int S1 = 36, S2 = 39, S3 = 34, S4 = 35, S5 = 32;

Adafruit_TCS34725 tcs(TCS34725_INTEGRATIONTIME_50MS, TCS34725_GAIN_4X);

const int CPR = 390;
const float DT_MS = 20;

double rpm_meas_1 = 0, rpm_meas_2 = 0;
double rpm_left = 0, rpm_right = 0;

// ===================== PID =====================
double Kp_1 = 0.19, Ki_1 = 11.0;
double Kp_2 = 0.20, Ki_2 = 11.0;
double integ_1 = 0, integ_2 = 0;

double base_rpm_set = 167.0;
double base_rpm = 160;
double Kp_line = 6.0, Ki_line = 0.80, Kd_line = 1.3;
double err_line = 0, last_err_line = 0, integ_line = 0;

// ===================== THỐNG KÊ =====================
double current_biggest_err = 0;
unsigned long missionStartTime = 0;
unsigned long finalTravelTime = 0;

// ===================== CALIB SENSOR (GIỮ NGUYÊN) =====================
/*
int rawMin[5] = {53, 43, 30, 33, 27};
int rawMax[5] = {3200, 2965, 2748, 2684, 2691};
*/
int rawMin[5] = {67, 57, 40, 40, 28};
int rawMax[5] = {3063, 2964, 2871, 2721, 2650};
// Lưu ý: Weight này bạn nói là mm thực tế
int weight[5] = {-24, -12, 0, 12, 24}; 
int norm_sensor[5];
/*
float redCalib[3]  = {47.8, 20.9, 14.9};
float blueCalib[3] = {38.0, 45.6, 38.6};
float unkCalib[3]  = {26.0, 24.0, 16.8};
*/
/*
float redCalib[3]  = {74.2, 30.5, 23.0};
float blueCalib[3] = {56.7, 68.1, 59.2};
float unkCalib[3]  = {66.2, 57.9, 50.9};
*/
/*
float redCalib[3]  = {84.3, 37.0, 29.5};
float blueCalib[3] = {74.0, 90.0, 81.7};
float unkCalib[3]  = {445.1, 457.5, 455.3};
*/
/*
float redCalib[3]  = {169.2, 44.2, 35.1};
float blueCalib[3] = {67.9, 106.5, 128.7};
float unkCalib[3]  = {77.4, 71.3, 61.1};
*/
/*
float redCalib[3]  = {187.3, 47.7, 38.4};
float blueCalib[3] = {83.3, 136.8, 172.4};
float unkCalib[3]  = {156.9, 149.3, 130.7};
*/
float redCalib[3]  = {176.7, 46.2, 36.6};
float blueCalib[3] = {77.7, 127.3, 158.7};
float unkCalib[3]  = {34.7, 28.8, 22.7};

int cargo_color = 0;

volatile long encCount1 = 0, encCount2 = 0;
long lastEnc1 = 0, lastEnc2 = 0;
unsigned long lastLoopTime = 0;
unsigned long lastTeleTime = 0;

enum RobotState { MOVING, STOP, WAIT_LOADING, INTERSECTION_DECISION, FINISH_SHIPPING };
enum ShippingStatus { WAIT_TO_START, MOVING_TO_LOADING, WAIT_AT_LOADING, MOVING_TO_INTERSECTION, MOVING_TO_ENDPOINT, FINISHED_DELIVERY, STOPPED_BY_USER };

RobotState currentState = STOP;
ShippingStatus currentShipStatus = WAIT_TO_START;

unsigned long stateStart = 0; 
int cargoColor = 0; 
bool isPickupZone = false, isIntersection = false, isFinish = false;
// ===================== ESP-NOW CALLBACK =====================
void OnDataRecv(const esp_now_recv_info_t * info, const uint8_t *incomingData, int len) {
  memcpy(&incomingCmd, incomingData, sizeof(incomingCmd));
  commandChar = incomingCmd.cmd;
  newCommandReceived = true;
}

// ===================== MOTOR HELPER =====================
void IRAM_ATTR encISR1() { if(digitalRead(PIN_ENC_B_1)) encCount1++; else encCount1--; }
void IRAM_ATTR encISR2() { if(digitalRead(PIN_ENC_B_2)) encCount2++; else encCount2--; }

void motorDrive(int pin1, int pin2, int pwmPin, int val){
  val = constrain(val, -1023, 1023);
  if(val > 0){ digitalWrite(pin1, HIGH); digitalWrite(pin2, LOW); }
  else if(val < 0){ digitalWrite(pin1, LOW); digitalWrite(pin2, HIGH); }
  else{ digitalWrite(pin1, LOW); digitalWrite(pin2, LOW); }
  ledcWrite(pwmPin, abs(val));
}

void setMotors(int left, int right){
  motorDrive(PIN_AIN1, PIN_AIN2, PIN_PWMA, left);
  motorDrive(PIN_BIN1, PIN_BIN2, PIN_PWMB, right);
}

int clampMap(int x, int in_min, int in_max, int out_min, int out_max){
  if(x <= in_min) return out_min;
  if(x >= in_max) return out_max;
  return (long)(x - in_min) * (out_max - out_min) / (in_max - in_min) + out_min;
}

void readLineSensors(){
  int pins[5] = {S1, S2, S3, S4, S5};
  for(int i = 0; i < 5; i++) 
    norm_sensor[i] = clampMap(analogRead(pins[i]), rawMin[i], rawMax[i], 0, 1000);
}

// ===================== LINE ERROR =====================
double getLineError() {
  long sumW = 0, sumV = 0;
  for (int i = 0; i < 5; i++) {
    sumW += norm_sensor[i] * weight[i];
    sumV += norm_sensor[i];
  }
  if (sumV < 300) return last_err_line;
  return (double)sumW / sumV;
}


// ===================== [NEW] ERR CENTER CALCULATION =====================
// Các thông số mới thêm vào
const float WHEEL_DIAMETER = 85.0; // mm
const float DIST_SENSOR_CENTER = 173.0; // mm
float last_err_center_filter = 0; // Biến lưu giá trị lọc

double getErrorCenter(double currentErr, double lastErr, float dt_sec, float avgRpm){
  double distMoved = (avgRpm / 60.0) * (WHEEL_DIAMETER * 3.14159) * dt_sec;
  if (distMoved < 1.0) return currentErr;
  double deltaErr = currentErr - lastErr;
  double tanTheta = deltaErr / distMoved;
  tanTheta = constrain(tanTheta, -1.0, 1.0);
  double raw_center_err = currentErr - (DIST_SENSOR_CENTER * tanTheta);
  float alpha = 0.2; //filter = 20%
  last_err_center_filter = (alpha * raw_center_err) + ((1.0 - alpha) * last_err_center_filter);
  return last_err_center_filter;
}

// ===================== COLOR =====================
float getDist(float r, float g, float b, float calib[3]) {
return sqrt(pow(r - calib[0], 2) + pow(g - calib[1], 2) + pow(b - calib[2], 2));
}

int detectColorRaw(){
  uint16_t r, g, b, c;
  tcs.getRawData(&r, &g, &b, &c);
  float fR = r, fG = g, fB = b;
  float dR = getDist(fR, fG, fB, redCalib);
  float dB = getDist(fR, fG, fB, blueCalib);
  float dU = getDist(fR, fG, fB, unkCalib);
  float minD = dR; int color = 1; 
  if(dB < minD){ minD = dB; color = 2; }
  if(dU < minD) color = 0; 
  return color;
}

void resetPID() {
  integ_1 = integ_2 = 0; integ_line = 0; last_err_line = 0;
  last_err_line = 0;
}
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
